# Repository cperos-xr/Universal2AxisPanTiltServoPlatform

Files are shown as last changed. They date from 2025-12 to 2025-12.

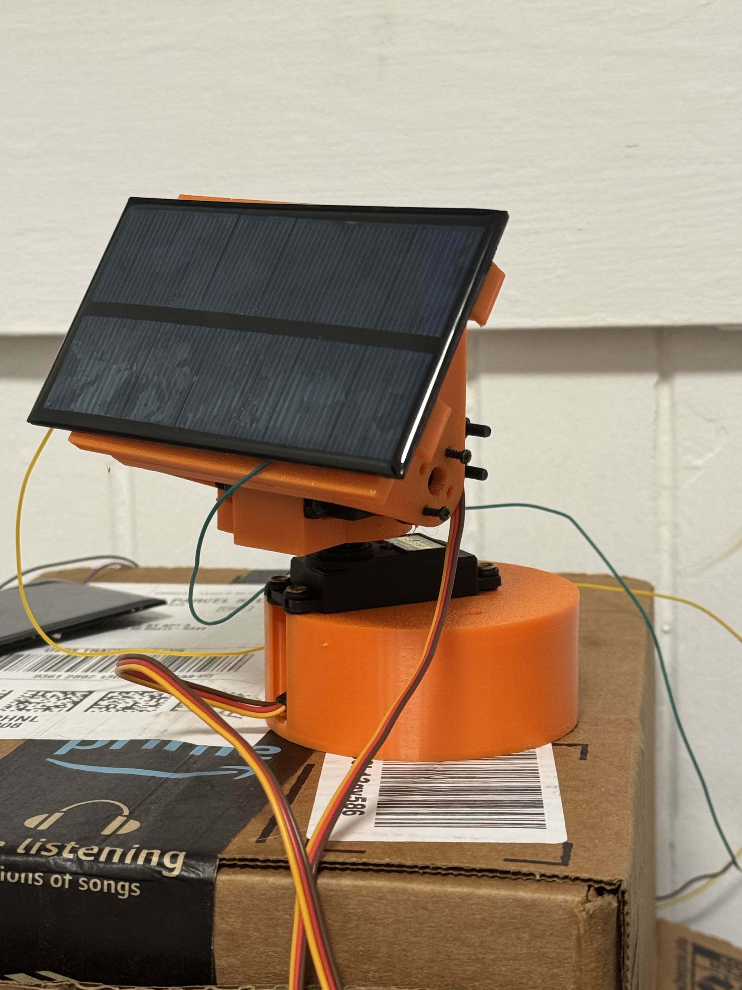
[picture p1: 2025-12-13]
pan_tilt_servo_platform/photos/solar.jpg

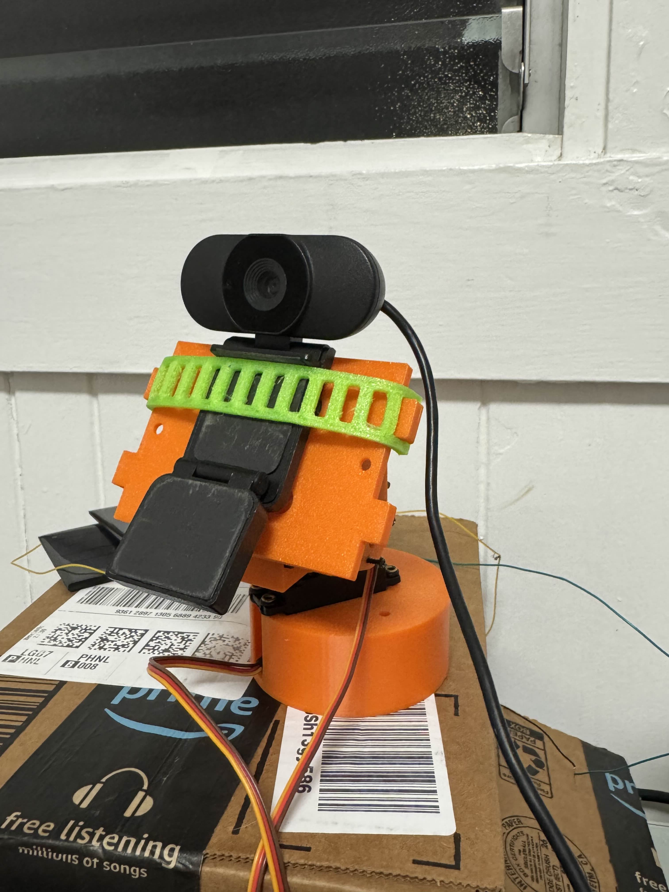
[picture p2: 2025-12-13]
pan_tilt_servo_platform/photos/webcam.jpg

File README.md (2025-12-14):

# Universal 2-Axis Pan–Tilt Servo Platform

This repository contains a **complete, modular 2-axis pan–tilt servo platform**, including mechanical designs, calibration utilities, and multiple control scripts.

The project is intentionally designed to support **both human control and automation**, and to scale cleanly into larger robotics or AI systems rather than being tied to a single use case.

---

## Repository Contents (Overview)

This repository includes **four major components**:

1. **3D Models** – Printable pan–tilt mount and hardware
2. **Calibration Script** – Used to determine safe servo limits before final assembly
3. **WASD Controller** – Human-friendly interactive control for testing and tuning
4. **PanTilt_JSON Controller** – Automation- and bot-friendly JSON-based controller

Each component serves a different role and can be used independently or together.

---

## Suitable Applications

This platform is suitable for:

- Robotic vision / AI computer vision experiments
- Face or object tracking systems
- Security or pet cameras
- Solar tracking panels
- Nerf turrets or automated launchers
- General pan–tilt robotics projects
- Any application requiring precise, scriptable 2-axis motion

The design supports **wide servo travel ranges** when properly calibrated.

---

## Hardware Overview

### Supported Hardware (Reference)

- Standard hobby servos (MG996R / MG995R class tested)
- ESP32 microcontroller (ESP32-C3 tested; others likely compatible)
- Camera, solar panel, or custom payload
- Standard 3-wire servo connections

---

## Servo Requirements & Setup Notes (Important)

⚠️ **Servo calibration is required before final assembly.** ⚠️  
Do not skip this step.

### Servo 1 — Pan (Side-to-Side)

- Intended for the **widest safe rotation range**
- Example tested range (MG996R-class):
  - **~500–2400 µs**

### Servo 2 — Tilt (Up / Down)

- Requires a **slightly reduced range** to avoid mechanical interference
- Example working range:
  - **~800–2050 µs**

⚠️ **Do not permanently mount the payload or platform to the servo horn until limits are verified.** ⚠️

### Calibration Recommendation

Before final assembly:
- Use the provided calibration script or equivalent test code
- Step each servo in **~50 µs increments**
- Identify mechanical bind or stress points
- Configure those values as hard limits in firmware

This ensures maximum usable travel without damaging hardware.

---

## Servo Horn Notes

- Designed around a **20 mm circular servo horn**
- MG996R / MG995R stock horns may vary slightly
- Plastic horns often work, but **metal or ceramic horns are strongly recommended** for:
  - rigidity
  - repeatability
  - durability under load

---

## 3D Models

The mechanical pan–tilt platform is designed to be **rigid and durable**, suitable for continuous motion.

### Recommended Print Settings (Tested)

- **Infill:** 25% gyroid
- **Walls:** 5–7 perimeters
- **Layer height:** 0.2 mm
- **Material:** PLA+ or PETG  
  - PETG recommended for outdoor or solar-tracking applications

Lower infill and wall counts may work for lighter-duty use, but testing showed minimal material savings compared to the increase in stiffness and reliability with these settings.

---

## Calibration Script

The calibration script exists to determine **safe microsecond limits** for each servo *before final assembly*.

Recommended workflow:
1. Upload calibration script
2. Sweep servos in **~50 µs increments**
3. Identify mechanical limits
4. Record safe min/max values
5. Use those values in control firmware

This step is critical to avoid binding, excessive torque, or servo damage.

---

## WASD Controller (Human-Friendly Control)

The WASD controller provides **real-time keyboard-based control**, intended primarily for:

- Initial testing
- Direction verification
- Mechanical tuning
- Manual experimentation

Typical controls:
- `W / S` → one axis
- `A / D` → the other axis
- Step size can be adjusted at runtime

> Note: Arduino Serial Monitor is not ideal for raw keypress input. A proper terminal application is recommended for best results.

---

## PanTilt_JSON Controller (Automation-Friendly)

`PanTilt_JSON` is a **JSON-based serial controller** intended for bots, scripts, and higher-level control systems.

It is designed to act as a **subsystem** in larger robotics or automation projects.

### Protocol Overview

The controller uses **JSONL (newline-delimited JSON)** over USB serial:

- One JSON object per line
- Each line must end with newline (`\n`)
- Each command must include `"cmd"`

Example:
```json
{"cmd":"help"}

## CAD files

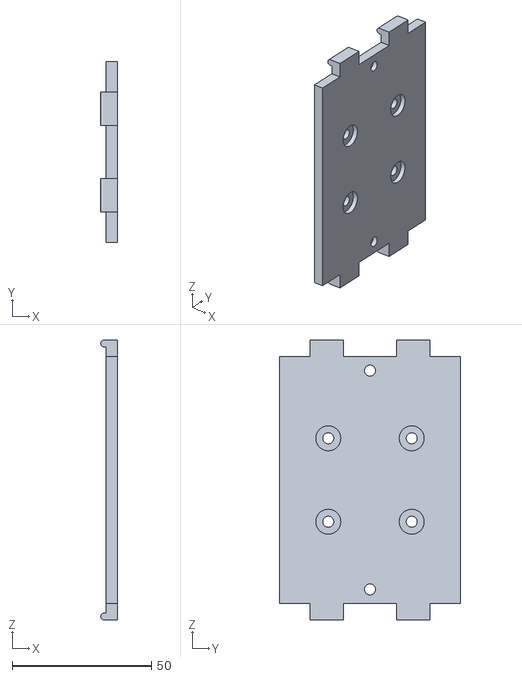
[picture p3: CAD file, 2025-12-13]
pan_tilt_servo_platform/photos/Plate Strap Adapter (large).stl
6.00 x 65.0 x 100.7

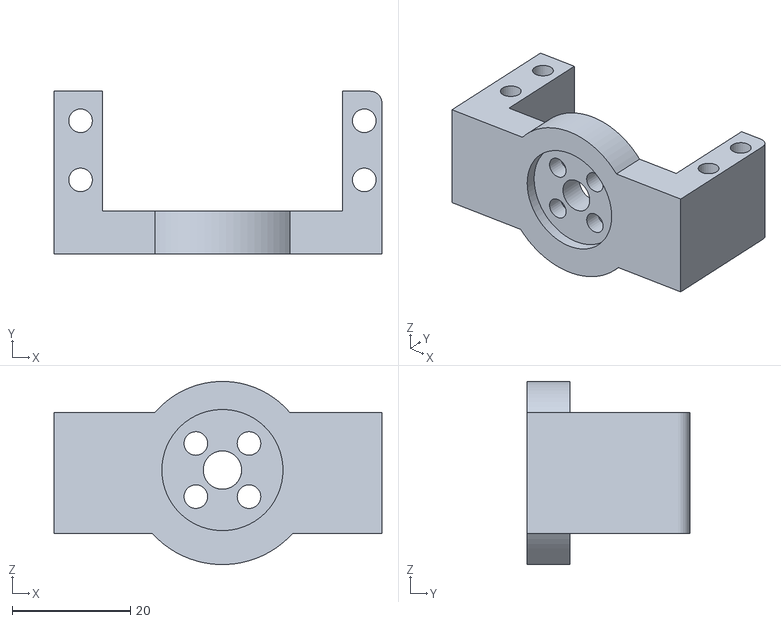
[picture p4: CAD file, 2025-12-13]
pan_tilt_servo_platform/photos/Servo Mount.stl
55.5 x 27.5 x 31.0

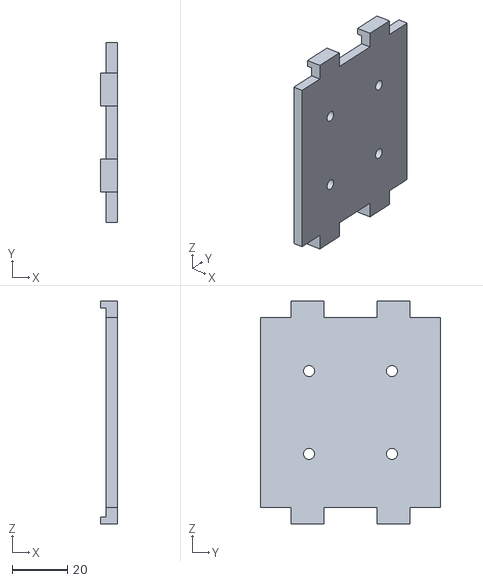
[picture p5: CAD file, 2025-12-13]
pan_tilt_servo_platform/photos/Plate Strap Adapter (small).stl
6.00 x 65.0 x 80.7

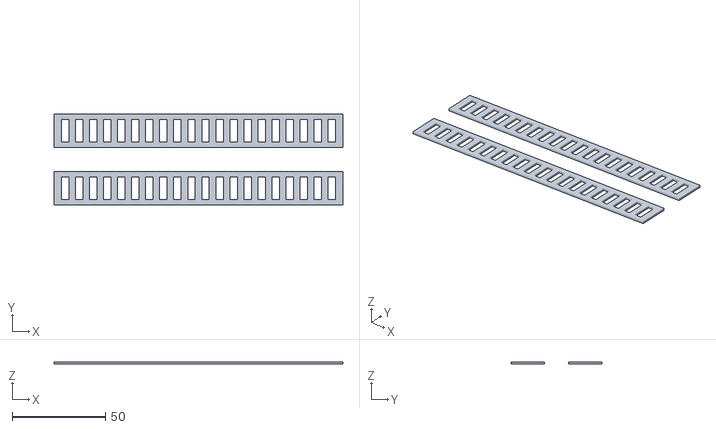
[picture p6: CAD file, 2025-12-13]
pan_tilt_servo_platform/photos/Strap (long thin).stl
155.0 x 49.0 x 1.25

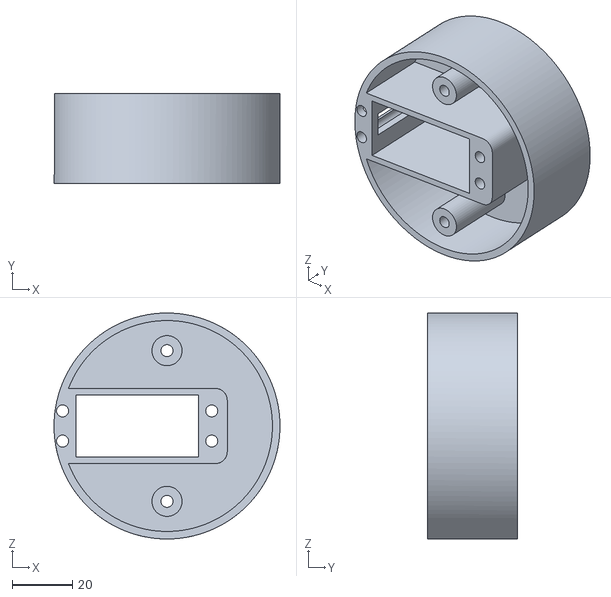
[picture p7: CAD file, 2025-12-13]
pan_tilt_servo_platform/photos/Circular Base.stl
75.0 x 30.0 x 75.0

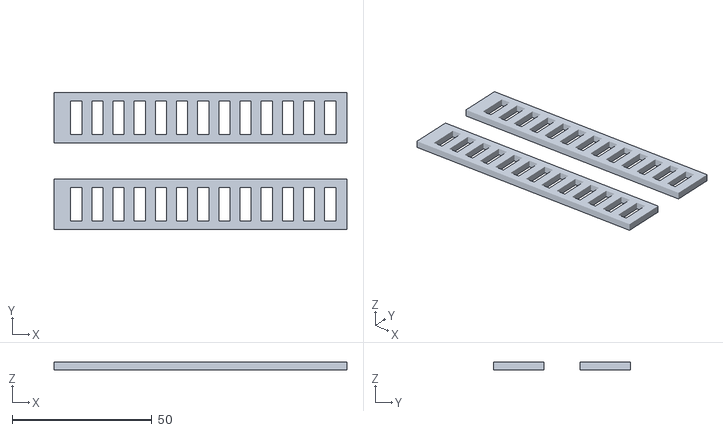
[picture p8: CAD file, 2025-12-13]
pan_tilt_servo_platform/photos/Strap (thick).stl
105.0 x 49.0 x 2.75

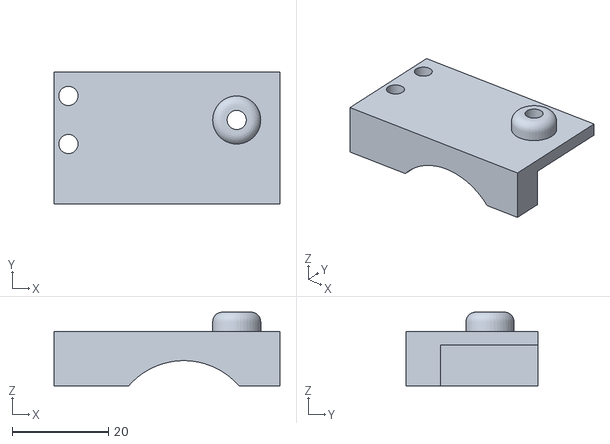
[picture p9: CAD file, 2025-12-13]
pan_tilt_servo_platform/photos/Servo Cap.stl
47.0 x 27.5 x 15.4

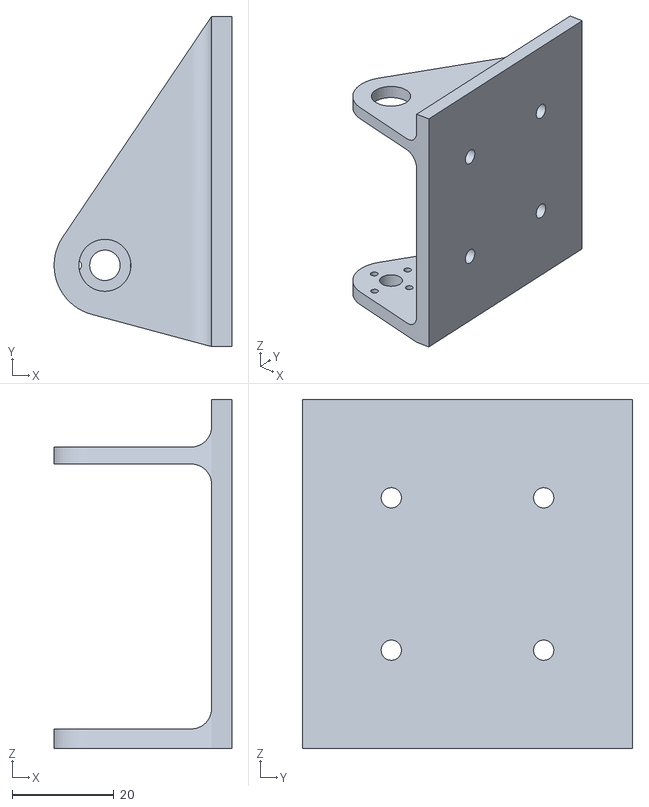
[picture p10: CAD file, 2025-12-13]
pan_tilt_servo_platform/photos/Plate.stl
35.0 x 65.0 x 68.7

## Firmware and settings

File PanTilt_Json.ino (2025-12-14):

// ------------------------------------------------------------
// PanTilt_JSON: 2-axis pan/tilt servo controller (ESP32-C3 tested)
// Protocol: JSONL (one JSON object per line, newline-terminated)
// No ArduinoJson dependency.
//
// Features:
// - set/adjust/center with dur or speed
// - stop/stopAll/resetAll
// - invert axis without jump
// - queue: off|on|step + qAdd/qClear/qAbort/qStatus/qList (use {"cmd":"queue","mode":"step"} for macros)
// - sweep macro (enqueues steps)
// - position favorites: save/recall (1..5)
// - command favorites (macros): favSave/favRun/favList/favClear (1..5), supports \\n multi-line scripts
// - persistence: persist + factoryReset using Preferences (NVS wear-leveled), versioned + CRC
//
// Notes:
// - "id" is optional command correlation id (for bots), NOT servo id
// - axis: x, y, xy
// - degrees are logical -90..+90
// ------------------------------------------------------------

#include <Arduino.h>
#include <ESP32Servo.h>
#include <Preferences.h>

// ------------------- Pins -------------------
// Use the pins that you already validated on your board.
// If 3/4 worked for you, keep them.
#define SERVO1_PIN 3  // X (pan)
#define SERVO2_PIN 4  // Y (tilt)

Servo s1, s2;

// ------------------- Calibrated safe ranges (microseconds) -------------------
static const int S1_MIN_US = 500;
static const int S1_MAX_US = 2400;

static const int S2_MIN_US = 800;
static const int S2_MAX_US = 2050;

// ------------------- Limits -------------------
static const float POS_MIN = -90.0f;
static const float POS_MAX =  90.0f;

// Avoid macro collisions with libc headers:
static const uint16_t CMD_LINE_MAX = 3600;

// Queue sizing (fixed for predictability)
static const uint8_t QMAX = 20;

// Timeout guard for queued steps
static const uint32_t STEP_TIMEOUT_GRACE_MS = 2000;

// Favorites
static const int POS_FAV_SLOTS = 5;
static const int CMD_FAV_SLOTS = 5;
static const uint16_t FAV_SCRIPT_MAX = 3600; // max stored macro length per slot

// ------------------- Runtime State -------------------
static float v1 = 0.0f;  // X degrees (logical)
static float v2 = 0.0f;  // Y degrees (logical)

static bool invX = false;
static bool invY = false;

// default speed in deg/sec when dur not specified
static float defaultSpeed = 90.0f;

// Position favorites
static bool posFavValid[POS_FAV_SLOTS] = {false,false,false,false,false};
static float posFavX[POS_FAV_SLOTS] = {0,0,0,0,0};
static float posFavY[POS_FAV_SLOTS] = {0,0,0,0,0};

// Command favorites (macros/scripts)
static bool cmdFavValid[CMD_FAV_SLOTS] = {false,false,false,false,false};
static String cmdFavScript[CMD_FAV_SLOTS] = {"","","","",""};

// Optional routing fields for master-script demux (echoed)
static String lastSubsystem = "";
static String lastRoute = "";

// Dirty flag for persistence (only written when persist is called)
static bool cfgDirty = false;

// ------------------- Motion Profiles -------------------
struct MoveProfile {
  bool active = false;
  float start = 0;
  float target = 0;
  uint32_t t0 = 0;
  uint32_t durMs = 0;
  uint32_t cmdRef = 0; // used for done events
  char axis = '?';
};

static MoveProfile mx, my;

// ------------------- Queue -------------------
enum QueueMode : uint8_t { Q_OFF=0, Q_ON=1, Q_STEP=2 };
static QueueMode qMode = Q_STEP;

struct QueueItem {
  bool used = false;
  uint32_t id = 0;

  String subsystem;
  String route;
  String kind;       // set/adjust/center/recall/sweep legs/etc.

  bool useX = false;
  bool useY = false;

  float tx = 0;
  float ty = 0;
  uint32_t dx = 0;
  uint32_t dy = 0;

  uint32_t expectedEnd = 0;
};

static QueueItem q[QMAX];
static uint8_t qHead = 0;
static uint8_t qTail = 0;
static uint8_t qCount = 0;

static bool qActive = false;
static QueueItem qCurrent;
static bool qCurXDone = true;
static bool qCurYDone = true;
static uint32_t qStartedAt = 0;

static uint32_t autoId = 0;

// ------------------- Preferences / Persistence -------------------
static Preferences prefs;
static const char* PREF_NS = "pantilt";
static const uint32_t CFG_MAGIC = 0x50544A31; // 'PTJ1'
static const uint16_t CFG_VERSION = 1;

struct PersistedConfig {
  uint32_t magic;
  uint16_t version;
  uint16_t reserved;
  float defaultSpeed;
  uint8_t invX;
  uint8_t invY;
  uint8_t posValidMask; // 5 bits
  uint8_t reserved2;
  float posX[POS_FAV_SLOTS];
  float posY[POS_FAV_SLOTS];
  uint32_t crc32;
};

// ------------------- Utilities -------------------
static float clampf(float x, float lo, float hi) { return (x<lo)?lo:((x>hi)?hi:x); }
static int clampInt(int x, int lo, int hi) { return (x<lo)?lo:((x>hi)?hi:x); }

static int mapSignedToUs(float v, int minUs, int maxUs) {
  v = clampf(v, POS_MIN, POS_MAX);
  int center = (minUs + maxUs) / 2;
  int halfRange = (maxUs - minUs) / 2;
  int us = center + (int)((v * halfRange) / 90.0f);
  return clampInt(us, minUs, maxUs);
}

static void applyOutputs() {
  float px = invX ? -v1 : v1;
  float py = invY ? -v2 : v2;

  int us1 = mapSignedToUs(px, S1_MIN_US, S1_MAX_US);
  int us2 = mapSignedToUs(py, S2_MIN_US, S2_MAX_US);

  s1.writeMicroseconds(us1);
  s2.writeMicroseconds(us2);
}

static uint32_t durationFromSpeed(float start, float target, float speedDegPerSec) {
  float sp = speedDegPerSec;
  if (sp < 0.1f) sp = 0.1f;
  float delta = fabsf(target - start);
  float sec = delta / sp;
  if (sec < 0.0f) sec = 0.0f;
  return (uint32_t)(sec * 1000.0f + 0.5f);
}

// Toggle invert with no physical jump:
static void toggleInvertX() { invX = !invX; v1 = -v1; cfgDirty = true; }
static void toggleInvertY() { invY = !invY; v2 = -v2; cfgDirty = true; }

// ------------------- CRC32 (simple, deterministic) -------------------
static uint32_t crc32_update(uint32_t crc, const uint8_t* data, size_t len) {
  crc = ~crc;
  for (size_t i=0;i<len;i++) {
    crc ^= data[i];
    for (int b=0;b<8;b++) {
      uint32_t mask = -(crc & 1u);
      crc = (crc >> 1) ^ (0xEDB88320u & mask);
    }
  }
  return ~crc;
}

// ------------------- Minimal JSON Helpers -------------------
static bool findKey(const String& s, const char* key, int& keyPos) {
  String pat = "\""; pat += key; pat += "\"";
  keyPos = s.indexOf(pat);
  return keyPos >= 0;
}

static bool getStringField(const String& s, const char* key, String& out) {
  int kp;
  if (!findKey(s, key, kp)) return false;

  int colon = s.indexOf(':', kp);
  if (colon < 0) return false;

  int q1 = s.indexOf('"', colon + 1);
  if (q1 < 0) return false;

  String tmp;
  tmp.reserve(128);

  bool esc = false;
  for (int i = q1 + 1; i < (int)s.length(); i++) {
    char c = s[i];

    if (esc) {
      // keep escaped char exactly once
      tmp += c;
      esc = false;
      continue;
    }

    if (c == '\\') {
      esc = true;
      continue;
    }

    if (c == '"') {
      out = tmp;
      return true;
    }

    tmp += c;
  }
  return false;
}

static void flushOut() {
  Serial.flush();
}

static bool getNumberField(const String& s, const char* key, float& out) {
  int kp;
  if (!findKey(s, key, kp)) return false;
  int colon = s.indexOf(':', kp);
  if (colon < 0) return false;

  int i = colon + 1;
  while (i < (int)s.length() && (s[i] == ' ' || s[i] == '\t')) i++;

  int j = i;
  while (j < (int)s.length()) {
    char c = s[j];
    if (c == ',' || c == '}' || c == ' ' || c == '\t' || c == '\r' || c == '\n') break;
    j++;
  }
  if (j <= i) return false;
  out = s.substring(i, j).toFloat();
  return true;
}

static bool getIntField(const String& s, const char* key, int& out) {
  float tmp;
  if (!getNumberField(s, key, tmp)) return false;
  out = (int)tmp;
  return true;
}

static bool getBoolField(const String& s, const char* key, bool& out) {
  int kp;
  if (!findKey(s, key, kp)) return false;
  int colon = s.indexOf(':', kp);
  if (colon < 0) return false;

  int i = colon + 1;
  while (i < (int)s.length() && (s[i] == ' ' || s[i] == '\t')) i++;

  if (s.startsWith("true", i))  { out = true;  return true; }
  if (s.startsWith("false", i)) { out = false; return true; }
  return false;
}

// Unescape only what we need for scripts: \\n \\r \\t \\\\ \\/ \\"
static String unescapeScript(const String& in) {
  String out; out.reserve(in.length());
  for (int i=0;i<(int)in.length();i++) {
    char c = in[i];

    // Handle \n, \r, \t
    if (c == '\\' && i+1 < (int)in.length()) {
      char n = in[i+1];

      // Normal escapes
      if (n == 'n') { out += '\n'; i++; continue; }
      if (n == 'r') { out += '\r'; i++; continue; }
      if (n == 't') { out += '\t'; i++; continue; }

      // If user sent \\n (double backslash form), treat it as newline too.
      if (n == '\\' && i+2 < (int)in.length()) {
        char n2 = in[i+2];
        if (n2 == 'n') { out += '\n'; i += 2; continue; }
        if (n2 == 'r') { out += '\r'; i += 2; continue; }
        if (n2 == 't') { out += '\t'; i += 2; continue; }
        if (n2 == '\\') { out += '\\'; i += 2; continue; }
      }

      // Other escapes we allow
      if (n == '\\') { out += '\\'; i++; continue; }
      if (n == '/')  { out += '/';  i++; continue; }
      if (n == '\"') { out += '\"'; i++; continue; }
    }

    out += c;
  }
  return out;
}


// ------------------- Reply Helpers -------------------
static void printRoutingFields(const String& subsystem, const String& route) {
  if (subsystem.length()) { Serial.print(",\"subsystem\":\""); Serial.print(subsystem); Serial.print("\""); }
  if (route.length())     { Serial.print(",\"route\":\"");     Serial.print(route);     Serial.print("\""); }
}

static void sendOk(uint32_t id, const String& subsystem, const String& route, const char* msg) {
  Serial.print("{\"ok\":true,\"id\":"); Serial.print(id);
  printRoutingFields(subsystem, route);
  Serial.print(",\"msg\":\""); Serial.print(msg); Serial.println("\"}");
  flushOut();
}

static void sendErr(uint32_t id, const String& subsystem, const String& route, const char* code, const char* msg) {
  Serial.print("{\"ok\":false,\"id\":"); Serial.print(id);
  printRoutingFields(subsystem, route);
  Serial.print(",\"error\":\""); Serial.print(code);
  Serial.print("\",\"msg\":\""); Serial.print(msg); Serial.println("\"}");
  flushOut();
}

static void sendState(const char* eventName, uint32_t ref, const String& subsystem, const String& route) {
  Serial.print("{\"ok\":true");
  if (eventName) { Serial.print(",\"event\":\""); Serial.print(eventName); Serial.print("\""); }
  if (ref) { Serial.print(",\"ref\":"); Serial.print(ref); }
  printRoutingFields(subsystem, route);

  Serial.print(",\"state\":{");
  Serial.print("\"x\":"); Serial.print(v1, 2);
  Serial.print(",\"y\":"); Serial.print(v2, 2);
  Serial.print(",\"invX\":"); Serial.print(invX ? "true":"false");
  Serial.print(",\"invY\":"); Serial.print(invY ? "true":"false");
  Serial.print(",\"speed\":"); Serial.print(defaultSpeed, 2);
  Serial.print(",\"moving\":{");
  Serial.print("\"x\":"); Serial.print(mx.active ? "true":"false");
  Serial.print(",\"y\":"); Serial.print(my.active ? "true":"false");
  Serial.print("}");

  Serial.print(",\"queue\":{");
  Serial.print("\"mode\":\"");
  Serial.print(qMode==Q_OFF?"off":(qMode==Q_ON?"on":"step"));
  Serial.print("\",\"count\":"); Serial.print(qCount);
  Serial.print(",\"active\":"); Serial.print(qActive ? "true":"false");
  Serial.print("}");

  Serial.print(",\"cfgDirty\":"); Serial.print(cfgDirty ? "true":"false");
  Serial.print("}}");
  Serial.println("}");
  flushOut();
}

static void sendEventDoneAxis(char axis, uint32_t ref, const String& subsystem, const String& route) {
  Serial.print("{\"ok\":true,\"event\":\"done\",\"axis\":\""); Serial.print(axis);
  Serial.print("\",\"ref\":"); Serial.print(ref);
  printRoutingFields(subsystem, route);
  Serial.println("}");
  flushOut();
}

static void sendEventStarted(const QueueItem& it) {
  Serial.print("{\"ok\":true,\"event\":\"started\",\"ref\":"); Serial.print(it.id);
  printRoutingFields(it.subsystem, it.route);
  Serial.print(",\"step\":{");
  Serial.print("\"kind\":\""); Serial.print(it.kind); Serial.print("\"");
  Serial.print(",\"axis\":\"");
  if (it.useX && it.useY) Serial.print("xy");
  else if (it.useX) Serial.print("x");
  else Serial.print("y");
  Serial.print("\"");
  if (it.useX) { Serial.print(",\"x\":"); Serial.print(it.tx, 2); }
  if (it.useY) { Serial.print(",\"y\":"); Serial.print(it.ty, 2); }
  Serial.print(",\"dx\":"); Serial.print(it.dx);
  Serial.print(",\"dy\":"); Serial.print(it.dy);
  Serial.print("}}");
  Serial.println("}");
  flushOut();
}

static void sendEventStepDone(const QueueItem& it) {
  Serial.print("{\"ok\":true,\"event\":\"stepDone\",\"ref\":"); Serial.print(it.id);
  printRoutingFields(it.subsystem, it.route);
  Serial.println("}");
  flushOut();
}

static void sendEventFault(const String& subsystem, const String& route, const char* code, uint32_t ref, const char* msg) {
  Serial.print("{\"ok\":false,\"event\":\"fault\",\"error\":\""); Serial.print(code);
  Serial.print("\",\"ref\":"); Serial.print(ref);
  printRoutingFields(subsystem, route);
  Serial.print(",\"msg\":\""); Serial.print(msg); Serial.println("\"}");
  flushOut();
}

// ------------------- Queue Ops -------------------
static bool qIsFull() { return qCount >= QMAX; }
static bool qIsEmpty() { return qCount == 0; }

static bool qEnqueue(const QueueItem& it) {
  if (qIsFull()) return false;
  q[qTail] = it;
  q[qTail].used = true;
  qTail = (uint8_t)((qTail + 1) % QMAX);
  qCount++;
  return true;
}

static bool qDequeue(QueueItem& out) {
  if (qIsEmpty()) return false;
  out = q[qHead];
  q[qHead].used = false;
  qHead = (uint8_t)((qHead + 1) % QMAX);
  qCount--;
  return true;
}

static void qClearAll() {
  for (uint8_t i=0;i<QMAX;i++) q[i].used = false;
  qHead = qTail = qCount = 0;
}

static void stopX() { mx.active = false; mx.durMs = 0; }
static void stopY() { my.active = false; my.durMs = 0; }
static void stopAllMotion() { stopX(); stopY(); }

static void abortQueueAndMotion() {
  stopAllMotion();
  qClearAll();
  qActive = false;
  qCurXDone = qCurYDone = true;
}

// ------------------- Motion Start -------------------
static void startMoveX(float target, uint32_t durMs, uint32_t ref) {
  target = clampf(target, POS_MIN, POS_MAX);
  if (durMs == 0) { v1 = target; mx.active = false; mx.durMs = 0; return; }
  mx.active = true;
  mx.start = v1;
  mx.target = target;
  mx.t0 = millis();
  mx.durMs = durMs;
  mx.cmdRef = ref;
  mx.axis = 'x';
}

static void startMoveY(float target, uint32_t durMs, uint32_t ref) {
  target = clampf(target, POS_MIN, POS_MAX);
  if (durMs == 0) { v2 = target; my.active = false; my.durMs = 0; return; }
  my.active = true;
  my.start = v2;
  my.target = target;
  my.t0 = millis();
  my.durMs = durMs;
  my.cmdRef = ref;
  my.axis = 'y';
}

static void executeStep(const QueueItem& it) {
  stopAllMotion();

  qCurXDone = !it.useX || (it.dx == 0);
  qCurYDone = !it.useY || (it.dy == 0);

  if (it.useX) startMoveX(it.tx, it.dx, it.id);
  if (it.useY) startMoveY(it.ty, it.dy, it.id);

  applyOutputs();
}

// ------------------- Parsing Helpers -------------------
static bool parseAxisMask(const String& axis, bool& useX, bool& useY) {
  String a = axis; a.toLowerCase();
  if (a == "x")  { useX = true;  useY = false; return true; }
  if (a == "y")  { useX = false; useY = true;  return true; }
  if (a == "xy") { useX = true;  useY = true;  return true; }
  return false;
}

static bool computeDurations(
  bool useX, bool useY,
  float tx, float ty,
  bool hasDur, float durSec,
  bool hasSpeed, float speedDegPerSec,
  uint32_t& dx, uint32_t& dy
) {
  if (hasDur) {
    if (durSec < 0.0f || durSec > 3600.0f) return false;
    uint32_t durMs = (uint32_t)(durSec * 1000.0f + 0.5f);
    dx = useX ? durMs : 0;
    dy = useY ? durMs : 0;
    return true;
  }

  float sp = hasSpeed ? speedDegPerSec : defaultSpeed;
  if (sp < 0.1f || sp > 1000.0f) return false;

  dx = useX ? durationFromSpeed(v1, tx, sp) : 0;
  dy = useY ? durationFromSpeed(v2, ty, sp) : 0;
  return true;
}

static QueueItem buildStepFromCommand(
  uint32_t id,
  const String& subsystem,
  const String& route,
  const String& cmd,
  const String& axis,
  const String& line,
  bool& ok,
  String& errCode,
  String& errMsg
) {
  ok = false;
  QueueItem it;
  it.id = id;
  it.subsystem = subsystem;
  it.route = route;
  it.kind = cmd;

  bool useX=false, useY=false;
  if (!parseAxisMask(axis, useX, useY)) {
    errCode = "bad_axis"; errMsg = "axis must be x, y, or xy";
    return it;
  }
  it.useX = useX; it.useY = useY;

  float durSec = -1.0f;
  float speed = -1.0f;
  bool hasDur = getNumberField(line, "dur", durSec);
  bool hasSpeed = getNumberField(line, "speed", speed);

  float tx=v1, ty=v2;

  if (cmd == "center") {
    tx = 0.0f; ty = 0.0f;
  } else if (cmd == "set" || cmd == "adjust") {
    float val=0, xVal=0, yVal=0;
    bool hasValue = getNumberField(line, "value", val);
    bool hasX = getNumberField(line, "x", xVal);
    bool hasY = getNumberField(line, "y", yVal);

    String a = axis; a.toLowerCase();
    if (a == "xy") {
      if (!hasX && !hasY && !hasValue) {
        errCode="missing_value"; errMsg="For axis=xy provide x and/or y (or value for both)";
        return it;
      }
      if (hasValue) { xVal = val; yVal = val; hasX = true; hasY = true; }
      if (cmd == "set") {
        if (hasX) tx = xVal;
        if (hasY) ty = yVal;
      } else {
        if (hasX) tx = v1 + xVal;
        if (hasY) ty = v2 + yVal;
      }
    } else {
      if (!hasValue) { errCode="missing_value"; errMsg="Provide: value (degrees)"; return it; }
      if (a == "x") tx = (cmd=="set") ? val : (v1 + val);
      else          ty = (cmd=="set") ? val : (v2 + val);
    }
  } else {
    errCode="unknown_cmd"; errMsg="Unknown motion cmd";
    return it;
  }

  tx = clampf(tx, POS_MIN, POS_MAX);
  ty = clampf(ty, POS_MIN, POS_MAX);
  it.tx = tx; it.ty = ty;

  uint32_t dx=0, dy=0;
  if (!computeDurations(useX, useY, tx, ty, hasDur, durSec, hasSpeed, speed, dx, dy)) {
    errCode="bad_timing"; errMsg="Invalid dur or speed";
    return it;
  }
  it.dx = dx; it.dy = dy;

  ok = true;
  return it;
}

// ------------------- Command Lists / Help / Examples -------------------
static void printCommands() {
  Serial.println("Commands (JSON objects, newline-terminated):");
  Serial.println("  {\"cmd\":\"commands\"}  -> short list");
  Serial.println("  {\"cmd\":\"help\"}      -> full reference");
  Serial.println("  {\"cmd\":\"examples\"}  -> copy/paste examples");
  Serial.println("  {\"cmd\":\"status\"}    -> state dump");
  Serial.println();
  Serial.println("Info: commands, help, examples, status");
  Serial.println("Motion: set, adjust, center, stop, stopAll, resetAll, invert, speed");
  Serial.println("Position favs: save, recall");
  Serial.println("Command favs: favSave, favRun, favList, favClear");
  Serial.println("Queue: queue, qAdd, qClear, qAbort, qStatus, qList");
  Serial.println("Macro: sweep");
  Serial.println("Persistence: persist, factoryReset");
}
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
void loop() {
  updateMotion();

  while (Serial.available() > 0) {
    char c = (char)Serial.read();
    if (c == '\r') continue;

    if (c == '\n') {
      String line = lineBuf;
      lineBuf = "";
      handleCommandLine(line);
    } else {
      if (lineBuf.length() < CMD_LINE_MAX) {
        lineBuf += c;
      } else {
        lineBuf = "";
        autoId++;
        sendErr(autoId, "", "", "line_too_long", "Command line exceeded buffer limit");
      }
    }
  }
}

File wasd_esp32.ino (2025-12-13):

// ------------------------------------------------------------
// Realtime “keyboard nudge” servo controller (two servos)
// ------------------------------------------------------------
// PURPOSE:
//   Control two servos interactively from a serial terminal by
//   pressing keys (ideally without pressing Enter).
//
// WHAT IT DOES:
//   - Maintains two signed command values v1 and v2 in degrees
//     where 0 = centered, range is -90..+90.
//   - Each keypress nudges v1/v2 by "step" degrees.
//   - Converts v1/v2 into calibrated microsecond pulse widths,
//     using each servo’s measured safe range.
//
// IMPORTANT:
//   Arduino Serial Monitor is often *not* good for realtime keypresses.
//   Use PuTTY / TeraTerm / CoolTerm if you want true "press keys" control.
// ------------------------------------------------------------

#include <Arduino.h>
#include <ESP32Servo.h>

Servo s1, s2;
#define SERVO1_PIN 3
#define SERVO2_PIN 4

// ------------------------------------------------------------
// Calibrated safe ranges (microseconds) measured earlier
//   Servo 1 is full-range:  500..2400
//   Servo 2 is narrower:    800..2050
//
// These are *hard limits* this program will never exceed.
// ------------------------------------------------------------

static const int S1_MIN_US = 500;
static const int S1_MAX_US = 2400;
static const int S2_MIN_US = 800;
static const int S2_MAX_US = 2050;

static int v1 = 0;   // -90..+90
static int v2 = 0;
static int step = 5; // degrees per keypress

static int clampInt(int x, int lo, int hi) {
  if (x < lo) return lo;
  if (x > hi) return hi;
  return x;
}

static void writeSigned(Servo& s, int v, int minUs, int maxUs) {
  v = clampInt(v, -90, 90);
  int center = (minUs + maxUs) / 2;
  int halfRange = (maxUs - minUs) / 2;
  int us = center + (v * halfRange) / 90;
  us = clampInt(us, minUs, maxUs);
  s.writeMicroseconds(us);
}

static void apply() {
  writeSigned(s1, v1, S1_MIN_US, S1_MAX_US);
  writeSigned(s2, v2, S2_MIN_US, S2_MAX_US);
  Serial.printf("v1=%d  v2=%d  step=%d\n", v1, v2, step);
}

void setup() {
  Serial.begin(115200);
  delay(600);

  s1.setPeriodHertz(50);
  s2.setPeriodHertz(50);
  s1.attach(SERVO1_PIN, 500, 2400);
  s2.attach(SERVO2_PIN, 500, 2400);

  apply();

  Serial.println("\nRealtime keys (no Enter if your terminal sends raw chars):");
  Serial.println("  w/s : servo1 + / -");
  Serial.println("  d/a : servo2 + / -");
  Serial.println("  space: center both");
  Serial.println("  [ / ]: step - / +");
}

void loop() {
  if (Serial.available() > 0) {
    char c = (char)Serial.read();

    switch (c) {
      case 'w': v2 -= step; break;
      case 's': v2 += step; break;
      case 'd': v1 -= step; break;
      case 'a': v1 += step; break;


      case ' ': v1 = 0; v2 = 0; break;

      case '[': step = clampInt(step - 1, 1, 30); break;
      case ']': step = clampInt(step + 1, 1, 30); break;

      default:
        // ignore other bytes (including CR/LF)
        return;
    }

    v1 = clampInt(v1, -90, 90);
    v2 = clampInt(v2, -90, 90);
    apply();
  }
}

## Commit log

2025-12-13 Enhance README with detailed setup and usage instructions
    Expanded the README to include detailed setup notes, servo requirements, and print settings for the Universal 2-Axis Pan–Tilt Servo Platform.
2025-12-13 Add ESP32 servo control functionality
2025-12-13 Add servo calibration utility for manual control
    This sketch allows manual control of two servos by sending microsecond pulse values over Serial. It includes setup instructions and clamps the pulse values to safe limits.
2025-12-13 Enhance comments for clarity on servo control
    Added comments explaining the purpose and functionality of the code.
2025-12-14 Revise README for clarity and additional details
    Updated the README to enhance clarity and detail about the universal 2-axis pan-tilt servo platform, including system overview, servo requirements, calibration recommendations, and firmware protocol.
2025-12-14 Revise README for improved project documentation
    Updated README to enhance clarity and detail about the project, including repository contents, suitable applications, hardware overview, calibration recommendations, and controller functionalities.
2025-12-14 Pesistence and Macros
    Macros work but long ones cant be sent with Arduino serial monitor, cmd seemed to work
